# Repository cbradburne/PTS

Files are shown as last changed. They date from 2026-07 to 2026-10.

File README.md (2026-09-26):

# PTS — Pan / Tilt / Slider

A five-mount motorised camera system for live video production — wireless,
self-healing, and controllable from everything in the booth: a PC app with
joystick and CV tracking, phones, a 7″ touchscreen, Stream Decks via Bitfocus
Companion, and QLab cue stacks.

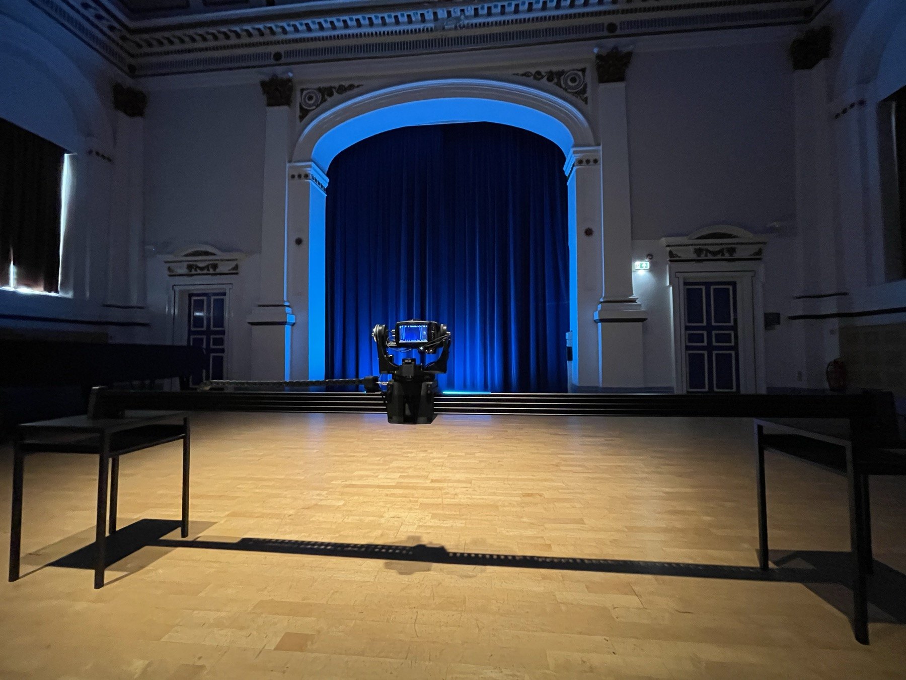
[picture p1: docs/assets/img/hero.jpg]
The rig in production — five mounts, hub console, one operator.


🌐 **[Project site](https://cbradburne.github.io/PTS/)** ·
📄 **[Two-page overview + OSC reference (PDF)](docs/PTS_Overview.pdf)** ·
🎛 **[Companion / QLab setup](docs/companion.md)** ·
📐 **[Look-at tracking design notes](DESIGN_V2.md)** ·
📡 **[What travels between a mount and the hub](docs/link_traffic.md)**

---

## What it does

- **Four axes per mount** — pan, tilt, slider, zoom (stepper or LANC) on
  TMC2209 silent drivers with StallGuard sensorless homing
- **Look-at tracking** — calibrate a subject's 3D position in two taps; the
  camera keeps aiming at it while the slider travels, and you can switch
  subjects mid-move from any controller
- **CV tracking** — the PC app watches the camera's feed and drives pan/tilt
  to keep a subject framed (optical-flow point tracking, or YOLO person
  detection with `ultralytics`); the operator keeps manual control of slider
  and zoom at the same time via a dedicated axis-mask jog mode
- **10 stored positions per mount** — recall from any surface at any speed
  preset; positions live on the mounts, so controllers can come and go
- **Zero-config pairing** — no MAC addresses, no per-unit firmware builds:
  hold a mount's screen, tap CAM 1–5, tap your hub. The hub learns mounts on
  first contact; conflicts resolve with one tap on the hub display
- **Self-healing** — autonomous recovery ladders on hub and mounts, idle
  maintenance restarts, watchdogs at every layer, and a motion-side dead-man:
  a mount stops within 500 ms of losing its control stream
- **Health telemetry** — every node reports heap, loop timing, link quality
  and reset cause into the PC log; degradation is visible hours before it
  becomes a symptom
- **Show-control** — OSC servers on both the hub and the PC app: every
  function on Companion buttons and QLab network cues

## Architecture

```mermaid
flowchart TB
    subgraph surfaces [Control surfaces]
        PC[PC app - PyQt6, joystick, CV tracking]
        WEB[Web app - phones]
        DISP[7in hub touchscreen]
        OSC[Companion / QLab - OSC]
    end
    HUB[HUB - Waveshare ESP32-S3-ETH<br/>Ethernet W5500 · WiFi AP PTS-name<br/>TCP 7777 · WebSocket · OSC 9700 · display UART]
    PC -- TCP / USB --> HUB
    WEB -- WebSocket --> HUB
    DISP -- UART --> HUB
    OSC -- UDP 9700 --> HUB
    HUB -- ESP-NOW star --> M1 & M2 & M3
    HUB -- Ethernet --> SAT[Satellite ESP32-S3-ETH<br/>one per distant room]
    SAT -- ESP-NOW --> M4 & M5
    subgraph mount [Each mount]
        M1[Bridge ESP32<br/>1.75in AMOLED]
        T1[Teensy 4.1 + TMC2209<br/>pan · tilt · slider · zoom]
        M1 -- UART --> T1
    end
    M2[CAM 2] ~~~ M3[CAM 3]
    M4[CAM 4] ~~~ M5[CAM 5]
```

| Part | Hardware | Firmware |
|---|---|---|
| Hub | Waveshare ESP32-S3-ETH (W5500 Ethernet, PoE variant) | [`firmware/esp32_hub_eth`](firmware/esp32_hub_eth) |
| Satellite | Waveshare ESP32-S3-ETH — extends ESP-NOW to another room over the wire | [`firmware/esp32_satellite`](firmware/esp32_satellite) |
| Hub display | Waveshare ESP32-S3 Touch LCD 7″ (800×480, LVGL 9) | [`firmware/esp32_display`](firmware/esp32_display) |
| Mount bridge | Waveshare ESP32-S3 Touch AMOLED 1.75″ (466×466 round, LVGL 9) | [`firmware/esp_mount_amoled175`](firmware/esp_mount_amoled175) |
| Motion controller | Teensy 4.1 @ 600 MHz, TMC2209 ×4, TeensyStep4 | [`firmware/teensy41_mount`](firmware/teensy41_mount) |
| PC app | Python 3.11+, PyQt6, OpenCV (+ optional YOLO) | [`pc_app`](pc_app) |
| Web app | Served by the hub itself — join its `PTS-<name>` WiFi | embedded in [`web_app.h`](firmware/shared/web_app.h) |

One binary per board type — **no per-unit configuration anywhere in source**.
Identity, pairing and calibration live in NVS/EEPROM, set from touchscreens.

## Hardware

Motion is NEMA 17 and NEMA 14 pancake steppers on TMC2209 drivers, geared with
GT2 belts and pulleys, off a single 12 V 8 A supply. The
[**bill of materials**](https://cbradburne.github.io/PTS/manual/bom.html) lists
every part with a buy link, broken down by assembly — circuit, mount, slider,
hub, display — including both the HDMI and SDI variants.

| | |
|---|---|
| [Bill of materials](https://cbradburne.github.io/PTS/manual/bom.html) | Motors, drivers, belts, pulleys, power, connectors, fasteners |
| [`Print Files/`](Print%20Files) | STEP models — PT mount and slider |
| [`PTS_4_PCB_2026-05-26.zip`](PTS_4_PCB_2026-05-26.zip) | PCB fabrication files |

> 🔧 *Still to write: assembly instructions, and a wiring diagram. The parts and
> the board are documented; how they physically go together is not.*

## Building the firmware

**Arduino IDE:** board settings and pinned library versions are documented in
[`libraries/README.md`](libraries/README.md) — copy the `libraries/` folders
into your Arduino libraries directory.

**Command line:** with `arduino-cli` installed (`brew install arduino-cli`),
one command compiles everything against the repo-pinned libraries:

```sh
tools/build.sh                      # every target
tools/build.sh hubeth display       # a subset
tools/build.sh flash hubeth [port]  # compile + upload
```

First-time bring-up: flash hubeth and the mounts, power up, then pair each mount
from its own screen (hold ~1.5 s → CAM number → pick hub → SAVE). The hub
needs no action. See the pairing sections in the firmware sources.

## Running the PC app

```sh
cd pc_app
python3 -m pip install -r requirements.txt
python3 -m pip install opencv-contrib-python   # + `ultralytics` for YOLO tracking
python3 main.py
```

Connects to the hub over USB serial or TCP (`Config` dialog). Includes
joystick control, position management, look-at calibration, CV tracking, and
an OSC server for Companion/QLab (UDP 9700).

## Show control (Companion / QLab)

Point a **Generic: OSC** connection at the hub (`192.168.4.1:9700`) or the
PC app machine — same `/pts/...` addresses on both, full reference in
[`docs/companion.md`](docs/companion.md) and the [PDF](docs/PTS_Overview.pdf).

```
/pts/cam/2/goto 3        recall shot 3 on camera 2
/pts/cam/1/jog -400 0 0 0   (press) … /pts/cam/1/jog/stop (release)
/pts/estop               stop everything
```

## Development

- **Protocol single source of truth** — [`firmware/shared/protocol.h`](firmware/shared/protocol.h)
  is canonical; `tools/check_protocol.py` verifies the Python and JS mirrors
  and cross-checks the *compiled C encoders* against the Python decoders
  byte-for-byte (golden vectors). Runs from the pre-commit hook:
  `git config core.hooksPath .githooks` after cloning.
- **Mount simulator** — develop the PC app with zero hardware:
  `python3 tools/mount_sim.py`, point the app at `127.0.0.1`. Includes a
  fault-injection console (link wedges, NACKs, packet loss) and `--selftest`.
- **Host test suites** — `tools/run_tests.sh` (or `tools/run_tests.sh cam` for a
  subset). No rig needed. Several of these read the FIRMWARE SOURCE and check
  the PC app against it — the command byte literals in `esp32_hub_eth.ino`, the
  loop-section enum in `esp32_satellite.ino` whose *order* is the wire
  encoding. That is deliberate: both halves of this rig have been wrong at the
  same time and agreed with each other, which is exactly what comparing one
  copy against another copy cannot catch.

  The end-to-end OSC test that lived here is gone with the PC app's OSC server —
  the OSC surface is the hub's now, so there is no host-side path to drive.

## Repository layout

```
firmware/
  shared/               canonical protocol, display UART framing, the web app
  esp32_hub_eth/        hub, for both boards: ESP-NOW star, AP, TCP/WS/OSC,
                        self-recovery — plus Ethernet and satellites on the
                        Waveshare ESP32-S3-ETH, WiFi-only on the XIAO ESP32S3
  esp32_satellite/      relay: extends ESP-NOW to another room over Ethernet
  esp32_display/        7" hub touchscreen (LVGL 9)
  esp_mount_amoled175/  mount bridge + round touchscreen, pairing UI
  teensy41_mount/       motion control: TMC2209, StallGuard, look-at solver
pc_app/                 PyQt6 controller: joystick, positions, look-at, CV, OSC
libraries/              pinned Arduino library versions (see its README)
tools/                  build.sh, protocol checker, simulator, tests, PDF gen
docs/                   Companion guide, overview PDF
Print Files/            STEP models        PTS_4_PCB_*.zip   PCB fab files
```

## License

**[PolyForm Noncommercial 1.0.0](LICENSE.md)** — in plain English:

- ✅ **Fork it, modify it, build it, share it** — free for any noncommercial
  purpose (personal, hobby, research, education), as long as the license and
  the copyright notice (which links back to this repository) stay with it.
- 💬 **Selling a product that uses any part of this?** That needs a separate
  commercial license — I'm open to discussion: contact
  [@cbradburne](https://github.com/cbradburne).

The license text in [LICENSE.md](LICENSE.md) is what governs; the bullets
above are just the summary.

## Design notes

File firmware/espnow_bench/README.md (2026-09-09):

# espnow_bench — finding the TX wedge

Two boards on a desk, both on USB serial, existing only to reproduce and then
kill the ESP-NOW transmit wedge that takes a mount off the air.

## What you need

| | board | why that one |
|---|---|---|
| **TX** — the mount | an **AMOLED** bridge board (spare, or one off a mount) | It is the board that wedges. The `load` experiment puts back the PSRAM/display work this firmware leaves out, and that only means something on the same silicon. |
| **RX** — the hub | **any ESP32-S3** — a hub-eth board, a satellite, or a plain S3 devkit | It only has to receive and ACK. It is not the suspect. |
| | **two USB cables to the same PC** | Both boards logged on one clock. See below — it is what answers the question. |

Nothing else. No Teensy, no display panel needed on the AMOLED, no hub, no
network. The two boards can sit a foot apart on a desk.

```bash
tools/build.sh flash bench   /dev/cu.usbmodemAAAA    # the AMOLED  (OPI PSRAM)
tools/build.sh flash benchrx /dev/cu.usbmodemBBBB    # the S3      (no PSRAM)
```

Two targets because the FQBNs differ — an AMOLED build flashed to a board with
no octal PSRAM does not boot. Same source either way.

### Which board needs to know what

Only the **TX** board needs a MAC typed at it. ESP-NOW registers a peer to
*send*; receiving needs nothing — an unencrypted frame reaches the receive
callback whatever the sender is, and the 802.11 ACK that decides the sender's
callback status is generated by the WiFi hardware for any frame addressed to
that MAC, before ESP-NOW is involved at all.

The RX board is passive by default. Turn `poll` on and it sends too — but it
still needs no MAC from you: it learns the TX board's address from the first
frame that arrives and registers that. There is no second MAC to get wrong.

What both boards **do** have to agree on is the **channel** (`chan`, default 1).
That is the one setting a silent link usually comes down to.

You do not need a separate terminal for any of this — **the logger types at both
boards for you** (see below), and it records what you typed into the run file.
Start it first, then set the boards up through it:

```
rx role rx                     # the receiver reboots and prints ITS OWN MAC
role tx
peer AA:BB:CC:DD:EE:FF         # <- that MAC. The RECEIVER's, not the TX's.
go
```

Plain text goes to the TX board; prefix with `rx ` for the receiver.

**`peer` is who the board sends TO.** On the TX board that is the *receiver's*
MAC — the one the RX board printed a moment ago. You never type a peer at the RX
board: passive it needs none, and polling it learns one. Typing the TX's own MAC
there is the easy mistake and it looks exactly like a dead radio, so the board
refuses it and says why.

On the RX board `role rx` makes it reboot and print its MAC, say it needs
nothing from you, and then:

- announces the first frame it gets, and which MAC it came from, so you know the
  link is up rather than guessing;
- if nothing arrives, says so every 30 s with its own MAC and channel, which is
  the check you would otherwise have to think of yourself.

On the TX board:

```
role tx
peer AA:BB:CC:DD:EE:FF
rate 50
go
```

Both boards persist their settings in NVS, so an overnight run survives a power
cut and resumes where it was. `help` lists every command.

### Reboot between leak runs

**`go` zeroes the counters. It does not give the stack back the buffers it
lost.** Only a chip reboot does — that has been the one fixed point of this
fault since August, and it applies to the bench exactly as it does to a mount.

So a second leak run on the same power cycle starts however many buffers down
the last one ended, with `floor` measuring from a false zero. It happened
immediately after the first reproduction: `go`, and `in_flight` read 3 from the
first sample to the last, never moving — the previous run's damage, not the new
run's. The board now says so when you `go` with a non-zero floor behind you.

Power cycle both boards, or `role tx` / `role rx` which reboot — then **`go` on
each**. `role` clears the run flag deliberately, so a board whose role just
changed does not come back transmitting; the cost is that the reboot looks like
the whole job and the pair comes up configured, linked and silent. Both boards
now say `STOPPED` on boot when that is where they are.

## Logging both boards

```bash
python3 -m pip install pyserial
tools/bench_log.py --tx /dev/cu.usbmodemAAAA --rx /dev/cu.usbmodemBBBB \
                   --tag cap0-rate50
```

(`python3 tools/bench_log.py …` works too, and is what to reach for if the
executable bit has not survived however the repo reached your machine.)

The logger holds both serial ports, so it is also the only thing that can talk
to the boards while it runs — type at it directly. `newfile [tag]` closes the
CSV and opens a fresh one **without touching the boards**, which is what you
want when the variable under test changes mid-session (`cap 2` on top of a load
that leaks, say). Restarting the logger would also start a new file, but it
drops the samples either side of the gap and resets the receiver baseline and
the deltas the arriving-without-callbacks alarm is built on. Each file names the
other, so neither is a fragment of unknown origin. Everything you type is
written into the CSV as well as onto the wire, which matters more than it
sounds: **"cap 1 at t=3600" is the single most important thing a comparison
needs, and the easiest to forget you did.** A run file that does not say what
was varied is not evidence.

One logger, both boards, one PC clock across the pair — which is not
convenience, it is the only way to ask the question the bench exists for:

**when the callbacks stop, are the frames still arriving?**

- **arriving, no callbacks** → the radio is fine and the *callback* is the fault.
  The pool leaks because buffers are never returned, not because sends fail.
- **frames stop too** → the transmit path really is down and the callback is
  telling the truth.

Those want opposite fixes, and the TX board alone cannot tell them apart — its
counters go quiet either way. The logger says which, in as many words, at the
end of every run.

Runs land in `bench-logs/` as CSV. Compare them:

```bash
tools/bench_log.py --compare bench-logs/*.csv
```

```
run                       mins   issued   lost  floor  rx_got  1st ref  wedged
cap0-rate50-...csv         9.8    30000  15000  14995   29500     410s    410s
cap1-rate50-...csv       840.0  2520000      3      0 2519997    never   never
```

That table is the deliverable. Two runs differing in one variable is a finding;
one run on its own is an anecdote.

## What the numbers mean

One line a second from the TX board:

```
t=612s issued=30600 cb_ok=30594 cb_fail=0 refused=0 nomem=0
       in_flight=6 floor=0 max=9 rx=0 heap=284512 err=0x0 cmd=1220 ack=1220 ovl=47
```

`cmd` is commands received, `ack` the replies sent for them, and **`ovl` is the
number of times `in_flight` went above 1** — two buffers out of the pool at once.
All three read 0 unless `poll` is on.

`ovl` is the first thing to look at with `poll` running. **`ovl` still 0 means no
overlap and the run is testing nothing new.** It is counted per transition and
sampled every loop pass, which matters: an overlap lasts about a millisecond, so
anything sampled once a second sees almost none of them.

It counts transitions above **the floor**, not above 1, so that it keeps meaning
the same thing once buffers start leaking. Measured against a fixed 1 it stopped
counting the moment the floor reached 2 — the first leak run froze `ovl` for its
last thirteen hours and read as "overlap stopped" when nothing of the sort had
happened.

**`in_flight = issued − (cb_ok + cb_fail)`** is the whole point. It is the number
of buffers `esp_now_send()` has taken from the stack's pool that the
send-complete callback has not yet given back.

- It bouncing between 0 and a few is **normal** — that is just sends in flight.
- **The heap is the second witness, and the one that settles an argument.** A
  real leak costs a fixed number of bytes per buffer and never gives them back
  — 208 on these boards, three times over in the run that reproduced it. A floor
  that rises while the heap returns to its old value is not a leak; it is a
  callback that came back late, or a `go` issued while sends were outstanding.
  Check both before believing either.
- **`floor` is the number to watch.** It is the lowest `in_flight` has returned
  to in the last five seconds, and it only ever rises. A floor that climbs and
  never comes down is buffers being *lost*, not buffers in use. That is the leak,
  and you are watching it happen — hours before `nomem` moves.
- `nomem` climbing means the pool is already empty. By then it is over.

The rig has never had `floor`. It only ever had `refused`, which cannot warn:
a refusal means the radio will not accept a send, so the report carrying the
number is the one thing that cannot go out. cam1's own health report 18 seconds
before it wedged read zero.

## Runs so far

**The third run reproduced it. It is the load.**

| run | config | for | sent | floor | outcome |
|---|---|---|---|---|---|
| `…0905-1822` | rate 50, cap 0, no load | 3.0 h | 542,067 | 0 | clean |
| `…0905-2313` | rate 200 + poll 20, cap 0, no load | 13.3 h | 10,512,753 | 0 | clean |
| `…0906-1238` | **the same, plus `load 40 100`** | 20.1 h | 10,123,186 | **0 → 4** | **LEAKED** |
| `…0907-0851` | `load 100 200`, cap 0 | 6.8 h | 2,944,102 | 0 | clean (short) |
| `…0907-1558` | **`load 40 100` + `cap 2`** | **53.3 h** | **26,868,324** | 0 | **clean** |

The third differs from the second in one thing: 40 ms of blocked loop in every
100. Same cap, same PHY, same peer, same boards, 10 million sends either way.

The fifth differs from the third in one thing: `cap 2`. Same load, same rate to
within 1% (140.0 sends/s against 138.6), same boards, same PHY.

**Run to 2026-09-09, 53.32 h, one continuous session:**

| | uncapped `…0906-1238` | `cap 2` `…0907-1558` |
|---|---|---|
| ran for | 20.09 h | **53.32 h** |
| sends | 10,123,186 | **26,868,324** |
| peak in flight | **7** | **2** |
| overlaps / 1000 sends | 43 | **101** |
| buffers lost | **4** | **0** |
| heap drift | **−832 B** | **0 B** |
| `cb_fail` / `refused` / `nomem` | — | **0 / 0 / 0** |

Not one callback missing in 26.9 million sends, and the heap ended on the same
byte it started: 265,724 → 265,724.

The uncapped run lost a buffer every 2.53 M sends. At that rate the capped run
should have lost **10.6**. It lost none: **p ≈ 2.4 × 10⁻⁵**, about 1 in 42,000.

And note the overlap column, because it answers the obvious objection. `cap 2`
did not win by transmitting less concurrently — it overlapped sends **more than
twice as often per send** as the run that leaked (101 per 1000 against 43). What
it bounded was the DEPTH. Sends overlapping is not the fault; three or more
overlapping is.

It has also now gone **8.9× the sends the uncapped run needed to lose its first
buffer** (3.0 M) without losing one. That is prevention, not delay — as far as
53 hours can show it.

### It needs BOTH, and that is the mechanism

| | load | peak in flight | result |
|---|---|---|---|
| 13.3 h | none | 5 | clean |
| **53.3 h** | 40/100 | **2** | clean |
| 20.1 h | 40/100 | **7** | **4 buffers gone** |

Blocking alone does not do it. Concurrency alone does not do it. Both together
do — and on the mount they are not independent, because **the block is what
creates the burst.**

`esp_mount_amoled175.ino:3525` drains the ESP-NOW receive queue unbounded:

```c
while (xQueueReceive(_espnow_rx_q, &en_msg, 0) == pdTRUE) {
    ... handle_hub_packet(pkt);      // an ACK per non-JOG packet, line 1357
}
```

`ESPNOW_RX_DEPTH` is 16. An LVGL flush blocks the loop; commands from the hub
queue up behind it; the loop resumes and fires up to sixteen ACKs back to back
with no cap and no pacing. That is a burst the average send rate (0.4/s idle,
10.4/s busy) gives no hint of, and it is exactly the condition these runs show
leaking.

**So the fix is on the mount and it is small: bound that drain.** Handling two
packets per loop pass instead of all sixteen leaves the rest queued for the next
pass microseconds later — no frames dropped, and never more than a couple of
sends outstanding. That is what `cap 2` did here.

Statistics, honestly: one run, zero events where about three were expected —
p ≈ 0.05. Suggestive on its own. What makes it more than suggestive is that the
mechanism is visible in the bridge's source.

### The signature

| | at | heap after | change |
|---|---|---|---|
| floor 0 → 1 | 5.97 h | 265,516 | **−208 B** |
| floor 1 → 2 | 6.28 h | 265,308 | **−208 B** |
| floor 2 → 3 | 15.17 h | 265,100 | **−208 B** |
| floor 3 → 4 | 20.04 h | 264,892 | **−208 B** |

**Exactly 208 bytes per lost buffer, four times, never returned** — 832 bytes
gone by the end of the run.

The control's heap moved 24 bytes in 13.3 hours and its floor never left 0. The
`cap 2` run did better still: **0 bytes in 53.3 hours**, ending on the same byte
it started.

This is what the field data pointed at all along: cam1 wedged twice on the
**strongest link on the rig** (−33 dBm) while cam4 sat at −68 dBm through a
satellite and never did. A radio explanation has that backwards. Starving the
loop does not.

### What it means for the mount

The mount renders 37 KB draw buffers out of PSRAM on this same chip. A blocked
loop is a blocked loop whether an LVGL flush or a `nop` spin is doing the
blocking — so the suspect is now the display work, not the radio, and the fix
is on that side: shorter flushes, yielding during them, or getting the ESP-NOW
callback out from behind the Arduino loop task.

Rate is explained too, and it was never really about the send count: more
traffic means more callbacks due during each block, and it is the callback that
returns the buffer. Cutting a satellite's traffic 88% cut its exposure by the
same factor — which is why that worked without anyone knowing why.

### Still open

- **Is it block length or duty cycle?** `load 40 400` (same 40 ms block, a
  quarter of the duty) against `load 10 100` (same duty, 10 ms blocks) separates
  them, and the answer decides the fix: if it is block length, chunking the
  flush is enough.
- **Does `cap` prevent it?** Fewer sends outstanding means fewer callbacks
  queued behind the block. §4 tests it directly, and it would be a small change
  to `espnow_tx()`.

First, though, make it faster — see §5.

### Read against the rig

cam1 wedged after 31.1 h and again after 11.4 h:

- The second run ran **longer than the shorter wedge** and sent **24× more
  frames** than cam1 could have managed in that time even at a flat-out
  10.4 sends/s. Not volume.
- It also stacked **486,030 overlapping sends, five buffers deep**, without
  losing a single one — 957,735 commands, 957,735 replies, none unanswered, and
  every send matched by its callback. Not concurrency, and not reply-on-arrival.
- `floor` sat at 0 for all 47,889 samples and the heap drifted **24 bytes in
  thirteen hours**. Whatever the mount is doing, this is not it.

Add 40 ms of blocked loop and it leaks in six hours at a *lower* send rate. So
none of volume, concurrency or reply-on-arrival is the mechanism — they are the
traffic the mechanism acts on.

Together with what was already known, the field is now:

| ruled out | how |
|---|---|
| RF / link quality | clean for hours at −80 dBm while collapsing at −76; cam1 wedges at −33 dBm, cam4 never at −68 dBm |
| BLE / WiFi coexistence | the wedge predates the Blackmagic code existing at all. Secondarily: the wedge logs come from the work rig, where cam1 has no camera paired, and an unbonded mount never scans |
| send volume | 542k sends, then 10.5M, nothing — and it later leaked at a *lower* rate |
| overlapping sends | 486k overlaps five deep, nothing |

| **confirmed** | **how** |
|---|---|
| **a blocked loop** | same rates, same cap, plus `load 40 100`: floor 0 → 3, 208 bytes gone each time, `in_flight` never below 3 again |

## The experiments, in order

Each one changes exactly one thing. Run the baseline first so you know what
"not wedging" looks like on your bench.

### 1. Baseline — does it reproduce at all?

```
cap 0        # fire and forget, exactly what the mount does today
rate 50
phy lr       # 1 Mbps long preamble, as the rig runs
load 0 0
scan 0
go
```

Leave it. The rig takes 11–31 hours; the bench may be faster because there is
nothing else competing. If `floor` stays at 0 for a day, the send stream alone
is **not** the cause and the answer is in one of the variables below.

**Done — clean.** 542,067 sends in 3.0 h, `floor` 0. The send stream alone is
not the cause.

### 2. Overlap — the one the first run pointed at

The baseline came back clean: **542,067 sends in 3 h at 50 Hz, `floor` 0, every
send answered by its callback.** That is more sends than cam1 could have made
before its 11.4-hour wedge even at a flat-out 10.4/s, so a plain per-send leak
is out.

But look at what that run could not test: **`in_flight` never once exceeded 1.**
Frames 20 ms apart, each clearing in about a millisecond — they never touch. One
buffer out of the pool, ever.

The rig is not shaped like that. The bridge runs reports on timers *and* answers
every non-JOG command the instant it arrives, so a command landing mid-report
puts a second buffer in the pool on top of the first. That happens all day on a
mount and had never once happened on this bench.

```
rx poll 20        # the RECEIVER sends commands; the TX must answer each
rx go             # the RX needs 'go' too now — it is sending
```

Both boards then report `cmd=` and `ack=`, and the TX prints **`OVERLAP`** the
first time two sends are outstanding at once. If it instead prints `NO OVERLAP
after 60s`, the run is still a metronome — raise `poll` until it does. Check
that in the first minute; it is the whole point of the run.

This also reconciles the two facts that otherwise fight each other. Overlap
scales worse than linearly with traffic, so an 88% cut removes far more than 88%
of it — which is how "rate matters" and "half a million evenly spaced sends did
nothing" can both be true.

`poll 0` restores the previous behaviour exactly, so the pair differs in one
variable.

**Done — clean.** 13.3 h at `rate 200` + `poll 20`: 10,512,753 sends, 486,030
overlaps up to five deep, `floor` 0, every command answered. Not concurrency.

One thing that run taught about tuning it: overlap does not scale smoothly with
the rates. Going from `rate 50`+`poll 20` to `rate 200`+`poll 20` — 4× the data
rate — took overlap from 0.05/s to **10.4/s**, roughly 200×. It behaves like a
threshold: at 20 ms spacing sends essentially never touch, at 5 ms they touch
constantly. So if `ovl` is not moving, raise `rate` rather than nudging `poll`.

### 3. Rate — is it really rate?

Cutting a satellite's traffic by 88% took it from 36 restarts in 17 hours to
zero, so rate is the strongest clue there is. Run `rate 10`, `rate 50`,
`rate 200` and record time-to-first-refusal for each. If the time scales with
rate, it is a per-send leak and the arithmetic will tell you the leak rate per
thousand sends.

Partly answered, and awkwardly: 220 sends/s for 13.3 h did nothing, so on the
bench rate does not reproduce what it plainly governs on the rig. Whatever rate
is a proxy for out there, it is not the send count and not the overlap.

### 4. The cap — is the fix three lines?

```
cap 1        # never a second send outstanding — the textbook ESP-NOW discipline
```

The mount today calls `esp_now_send()` with no regard for how many sends are
outstanding, and `espnow_tx()` says so in as many words: *"none of them can do
anything useful about a refusal in the moment"*. If `cap 1` (or 2, or 4) stops
the floor rising where `cap 0` does not, **that is the fix**, and it is a small
change to `espnow_tx()`.

Worth running now that §5 gives something to prevent: keep `load 40 100` and add
`cap 2`. Fewer sends outstanding means fewer callbacks queued behind each block.
A run that leaks without a cap and not with one is the whole answer.

### 5. Load — is it the display, not the radio?  ← **THIS ONE REPRODUCED IT**

Everything above came back clean, which promoted this one: it was the largest
thing the bench did not have. `rate 200` and `poll 20` left exactly as they
were, so the 13.3 h clean run is its control and load the only difference.

**Result: floor 0 → 3 in 20 h, 208 bytes gone each step.** See *Runs so far*.

What is left is to make it FASTER, because every experiment from here costs a
night at six hours to first leak. Push the block length up:

```
load 100 200     # 100 ms blocks, half the time
```

If time-to-first-leak drops with it, that is both a faster bench and evidence
that block length — not duty cycle — is the variable. Then `load 40 400`
(same block, quarter the duty) against `load 10 100` (same duty, short blocks)
separates the two properly, and the answer decides the fix on the mount: if it
is block length, chunking the LVGL flush is enough.

```
cap 0
load 40 100      # block the loop 40 ms in every 100 — a heavy LVGL flush
```

The mount renders 37 KB draw buffers out of PSRAM on this same chip, and the
firmware already notes that rendering is bandwidth-bound. If starving the loop
leaks buffers, the display is the cause and the radio is innocent.

**This is the hypothesis the field data points at.** cam1 wedged twice at
−33 dBm — the strongest link on the rig — while cam4 sat at −68 dBm through a
satellite and never did. A radio-quality explanation has that backwards; a
"cam1's screen is doing more work" explanation does not.

Try `load 10 100`, `40 100`, `100 200`. If there is a threshold, find it.

### 6. Scan — does retuning the radio drop callbacks?

```
load 0 0
scan 30
```

A scan retunes the radio out from under an in-flight send.

Read the history before spending a night on it. The mount used to scan every
five minutes for the life of the run, and that was found and removed — an
overnight log caught **174 failures, one every 300 s to the second**, phase
locked to the mount's boot, ~100–150 `txfail` in a burst each time. But those
were the hub misreading a run of failures as a wedge and refreshing the peer,
not the NO_MEM fault: `esp_mount_amoled175.ino` around the `[REACQ]` block has
the whole account.

Since then the bridge scans only **at boot** or when its base has gone
**silent**, so a mount with a healthy hub link does not scan at all. That makes
it a poor fit for cam1, whose link was the strongest on the rig — unless the
link went quiet first, which is worth checking in the logs before testing it
here.

### 7. PHY rate

```
phy def      # then reboot
```

1 Mbps with a long preamble buys 6–10 dB of range and makes every frame roughly
eight times longer on air. Longer frames mean longer in flight, and more of them
outstanding at the same send rate.

## What a finding looks like

Something that separates two runs differing in one variable, with a mechanism:

> `cap 0` at 50 Hz: floor reaches 11 in 40 minutes, first refusal at 71 min.
> `cap 1` at 50 Hz: floor 0 after 14 hours.
> → the leak is per-outstanding-send, and bounding in-flight prevents it.

That is enough to change `espnow_tx()` and put a number on the expected
improvement before touching the rig.

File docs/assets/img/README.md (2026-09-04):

# Site images

Drop photos/screenshots here with these exact filenames and the matching
slot on the site fills itself in (no HTML edits needed):

| File | Where it appears |
|---|---|
| `hero.jpg` | Hero — the rig in production (landing page) |
| `mount-pole.jpg` | Mounts — head on a clamp, built without the slider |
| `mount-home.svg` | Mounts — the round AMOLED status screen |
| `hub-home.svg` | Hub — the 7" touchscreen home screen |
| `phone-landscape.png` | Hub — the web app on a phone |
| `lookat-move.mp4` | Look-at — a move mid-travel (video, with `.jpg` poster) |
| `cv-window.png` | CV tracking — the tracking window with a lock-on target |
| `pc-app.png` | Control surfaces — PC app screenshot |
| `move-panel.png` | Control surfaces — the Move panel |
| `cad.png` | Build it — CAD model |
| `pcb.jpg` | Build it — the mount PCB |

Landscape ~1600px wide works best; JPG for photos, PNG for screenshots.

## Video

Clips are 960×540 H.264 MP4, no audio, `-movflags +faststart`, ~1.5 MB per
40 s — small enough to sit in the repo, and they play inline everywhere
(`muted` + `playsinline` is what lets iOS Safari play them in the page). Each
has a same-named `.jpg` poster frame, pulled from the encoded clip.

Keep the **camera master out of git** — `docs/assets/img/*.mov` is gitignored.
Binaries don't delta-compress, so a master committed once stays in history
forever. Encode to MP4 in a scratch directory, check it, then commit only the
final file. To re-encode from a master:

```
ffmpeg -ss <start> -to <end> -i master.mov -an \
  -vf "fps=24,scale=960:540:flags=lanczos" \
  -c:v libx264 -preset slow -crf 31 -pix_fmt yuv420p \
  -profile:v main -movflags +faststart -g 48 out.mp4
```

## Manual pages

Pages under `docs/manual/` use the same self-filling photo-slot convention.
So far:

| File | Where it appears |
|---|---|
| `rig-overview.jpg` | Getting started — a whole rig |
| `mount-home.svg` | The mounts — round AMOLED status screen |
| `mount-level.svg` | The mounts — spirit-level screen |
| `mount-setup.svg` | The mounts + Pairing — Setup screen |
| `hub-home.svg` | Hub touchscreen — home screen (hero) |
| `hub-positions.svg` | Hub touchscreen — Positions screen |
| `hub-detail.svg` | Hub touchscreen — per-camera control |
| `hub-config.svg` | Hub touchscreen — Config screen |
| `hub-pairing.svg` | Hub touchscreen — Paired Mounts |
| `phone-portrait.png` | Web app — phone in portrait (hero) |
| `phone-landscape.png` | Web app — phone in landscape |
| `ipad-landscape.png` | Web app — extended view on a tablet |
| `lookat-move.mp4` | Look-at — a full move, camera POV |
| `lookat-reaim.mp4` | Look-at — re-aiming to a second subject mid-move |
| `slider-rail.mp4` | The mounts — the head travelling its rail |
| `mount-rail.jpg` | The mounts — the head on its slider rail |
| `mount-pole.jpg` / `mount-pole2.jpg` | The mounts — the slider-less clamp build |
| `slider-production.mp4` | The mounts — slider move during a live set |
| `slider-venue.mp4` | The mounts — the same rig from the back of the hall |

The hub and mount screens are SVG recreations of the 7" console and the 1.75"
round AMOLED rather than photographs — they stay crisp at any size and are far
smaller than a photo of a panel. Round mount screens use the `round` figure
class so the square artwork is capped and centred. The
phone/tablet web-app shots are clean screen captures, so PNG. More slots will be
added as manual sections are written.

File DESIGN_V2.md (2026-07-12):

# Camera Mount Controller — Version 2 Design

## What's new in v2

V2 adds **look-at tracking**: the camera continuously aims at a named subject
in 3D space while the slider moves independently.  Pan and tilt become
*derived* values — computed from the current slider position and the
subject's calibrated 3D world coordinates — rather than independent motor
targets.

V1 is preserved in `/Users/col/New CC` and remains fully functional.

---

## Coordinate system

```
                         Z  (away from rail, into room)
                         │
               subject ──┼──────────────────●  (sx, sy, sz)
                         │               ╱
                         │            ╱  look-at vector
                         │         ╱
  Y (up)                 │      ╱
    │                    │   ╱
    │   slider rail ─────●──────────────────▶  X (along rail)
    │                  cam at
    └──────────────────  (slider_pos, cam_height, 0)
```

- **X axis** — along the slider rail; 0 = slider home (min limit)
- **Y axis** — vertical; 0 = camera pivot height (set at calibration)
- **Z axis** — perpendicular to rail, into the room (positive = toward subjects)
- All units: **millimetres**

### Look-at angles

Given current camera position `(cx, 0, 0)` and subject `(sx, sy, sz)`:

```
dx = sx - cx
dz = sz          (camera Z is always 0)
dy = sy          (camera Y pivot is 0 by definition)

pan_rad  = atan2(dx, dz)                       // horizontal
tilt_rad = atan2(dy, sqrt(dx*dx + dz*dz))      // vertical
```

These are converted to motor steps using the existing
`physToUSteps` / degrees-to-steps calibration.

---

## Subjects vs Slider Locations

The 10-slot grid is split into two independent concepts:

| Concept | Count | Stored on | Description |
|---|---|---|---|
| **Subjects** | up to 8 | Teensy EEPROM | 3D world coords of a person/object |
| **Slider moves** | up to 8 | Teensy EEPROM | Slider start+end position + speed |

A **shot** combines one slider move with one subject: "move the slider from
A to B while keeping the camera aimed at Subject 3."  Shots can be chained.

---

## Subject calibration workflow

1. User presses **"Add Subject"** (PC / hub / web)
2. Firmware auto-moves slider to `slider_min` (home)
3. UI prompts: *"Aim camera at subject, then press SET"*
4. User jogs pan/tilt to subject, presses SET →
   firmware records `(slider_pos_A, pan_steps_A, tilt_steps_A)`
5. Firmware auto-moves slider to `slider_max`
6. UI prompts: *"Re-aim camera at same subject, then press SET"*
7. User jogs pan/tilt, presses SET →
   firmware records `(slider_pos_B, pan_steps_B, tilt_steps_B)`
8. Firmware solves for `(sx, sy, sz)` from the two observations and saves
   to EEPROM.

### Solving for 3D position from two observations

At slider pos `xA`, camera aims along unit vector `vA`.
At slider pos `xB`, camera aims along unit vector `vB`.

Two rays in 3D space; solve for their nearest intersection
(least-squares, since real measurements won't be perfect):

```
Ray A:  P = (xA, 0, 0) + t * vA
Ray B:  P = (xB, 0, 0) + s * vB
```

This is a standard ray-ray closest-point problem solved with a 2×2 linear
system.  The midpoint of the shortest segment between the two rays is the
estimated subject position.

---

## New firmware state machine

```
STATE_IDLE
STATE_JOGGING            (unchanged from v1)
STATE_MOVING_TO_POS      (unchanged — used for simple GOTO)
STATE_FINDING_LIMITS     (unchanged)
STATE_LOOK_AT_MOVE       (NEW)
  └─ slider moves on its own profile
  └─ pan/tilt updated every LOOK_AT_INTERVAL_MS from current slider pos
  └─ subject can be switched mid-move (pan/tilt smoothly steers)
  └─ pan/tilt speed capped at LOOK_AT_MAX_PT_DEG_S (configurable)
STATE_CALIBRATING_SUBJECT (NEW)
  └─ sub-states: WAITING_POINT_A → MOVING_TO_B → WAITING_POINT_B → SOLVING
```

---

## Look-at controller (replaces moveTo for pan/tilt during a slider move)

Runs every `LOOK_AT_INTERVAL_MS` (20 ms = 50 Hz) inside `update()`:

```cpp
void MountMotion::_updateLookAt() {
    // 1. Get current slider position in mm
    float cx = stepsToMm(AXIS_SLIDER, _stepper[AXIS_SLIDER]->getPosition());

    // 2. Compute required pan/tilt angles
    float dx = _lookat_subject.x - cx;
    float dy = _lookat_subject.y;        // constant vertical offset
    float dz = _lookat_subject.z;

    float pan_rad  = atan2f(dx, dz);
    float tilt_rad = atan2f(dy, sqrtf(dx*dx + dz*dz));

    // 3. Convert to steps
    int32_t pan_target  = radToSteps(AXIS_PAN,  pan_rad);
    int32_t tilt_target = radToSteps(AXIS_TILT, tilt_rad);

    // 4. Speed-limited move toward target (follower-style)
    _driveTowardTarget(AXIS_PAN,  pan_target,  _lookat_max_pt_speed);
    _driveTowardTarget(AXIS_TILT, tilt_target, _lookat_max_pt_speed);
}
```

`_driveTowardTarget()` uses `rotateAsync()` + `overrideSpeed()` with a
speed proportional to distance, capped at `_lookat_max_pt_speed`.

---

## Pan/tilt absolute angle reference

### The problem

Pan and tilt have no hardware end stops.  On every power cycle the step
counter resets to zero at whatever physical position the head is in.  For
look-at tracking to work, the firmware must know: *"at this step count, the
camera is physically pointing at this angle."*

### How deg/step is established (once, at first calibration)

During subject calibration (2-point process), two observations of the same
subject from different slider positions give two known pan angles and two
known tilt angles with their corresponding step counts.  This yields:

```
pan_deg_per_step  = (pan_B_deg  - pan_A_deg)  / (pan_steps_B  - pan_steps_A)
tilt_deg_per_step = (tilt_B_deg - tilt_A_deg) / (tilt_steps_B - tilt_steps_A)
```

These are stored in EEPROM and never need recalculating unless the
mechanical drive ratio changes (e.g. gears replaced).

### The session reference ("Set Ref")

`deg_per_step` tells us the *scale* but not the *offset* — i.e. where in
physical angle terms step-count-zero currently sits.  This offset is
invalidated whenever the mount is powered off, or whenever someone physically
moves the head while powered on.

**Solution: a "Set Ref" button, available at any time from all interfaces.**

Workflow:
1. Operator aims the camera at any already-calibrated subject (or any known
   reference point with a stored subject record).
2. Presses **Set Ref** and selects the subject they are aimed at.
3. Firmware calculates the expected pan/tilt angles for the current slider
   position looking at that subject's 3D coords, then sets the step-count
   offset so the current step count maps to those angles.

There is no timer.  The button can be pressed:
- At the start of a session after powering on
- After physically repositioning the head
- Any time the operator suspects the reference has drifted
- Repeatedly on different subjects to verify consistency

If the reference is slightly off on the first try, the operator simply
re-aims and presses Set Ref again.  No move is commanded — the button only
updates the internal angle offset.

### Future: optical homing (Option A, hardware upgrade path)

Adding an optical end stop to pan and/or tilt would allow automatic homing
on power-on, making the Set Ref step unnecessary.  The firmware architecture
is designed to accommodate this — `setRef()` would simply become an
internally-called function after the home move completes rather than a
user-triggered one.  This will be investigated separately.

---

## New protocol commands (additions to v1)

| Command | Direction | Payload | Description |
|---|---|---|---|
| `CMD_ADD_SUBJECT_START` | PC→Mount | `subject_id (1B)` | Begin calibration for subject N |
| `CMD_ADD_SUBJECT_SET_A` | PC→Mount | — | Record point A (slider at home, pan/tilt current) |
| `CMD_ADD_SUBJECT_SET_B` | PC→Mount | — | Record point B (slider at max, pan/tilt current) |
| `CMD_ADD_SUBJECT_ABORT` | PC→Mount | — | Cancel calibration |
| `CMD_DELETE_SUBJECT` | PC→Mount | `subject_id (1B)` | Delete a subject |
| `CMD_SUBJECT_LIST` | Mount→PC | 8 × `{id, name[16], x,y,z floats}` | All subjects |
| `CMD_SET_REF` | PC→Mount | `subject_id (1B)` | Set pan/tilt angle reference using named subject at current slider pos |
| `CMD_SET_SLIDER_MOVE` | PC→Mount | `slot, start_mm, end_mm, speed_preset` | Store a slider move |
| `CMD_START_LOOK_AT_MOVE` | PC→Mount | `slider_slot, subject_id, max_pt_speed` | Start tracking move |
| `CMD_SWITCH_SUBJECT` | PC→Mount | `subject_id` | Switch target mid-move |
| `CMD_LOOK_AT_STATUS` | Mount→PC | `slider_pos_mm, pan_deg, tilt_deg, subject_id` | Live telemetry |
| `CMD_REF_CONFIRMED` | Mount→PC | `pan_deg, tilt_deg (2× float)` | Echoes computed reference angles so UI can confirm |

---

## EEPROM additions (v2)

```c
#define MAX_SUBJECTS   8
#define MAX_SLIDER_MOVES 8
#define SUBJECT_NAME_LEN 16

typedef struct {
    float x, y, z;           // world coords in mm
    char  name[SUBJECT_NAME_LEN];
    bool  valid;
} SubjectRecord;

typedef struct {
    int32_t start_steps;
    int32_t end_steps;
    uint8_t speed_preset;
    bool    valid;
} SliderMoveRecord;

// Added to EepromConfig:
SubjectRecord    subjects[MAX_SUBJECTS];
SliderMoveRecord slider_moves[MAX_SLIDER_MOVES];
float            slider_mm_per_step;   // set during findLimits (mm travel / total steps)
float            pan_deg_per_step;     // set during first subject calibration
float            tilt_deg_per_step;    // set during first subject calibration
```

The **session reference** (pan/tilt step-count offset) is held in RAM only —
it is intentionally not saved to EEPROM because it is always invalid after a
power cycle.  The operator sets it via the **Set Ref** button each session.

```c
// RAM only — not in EepromConfig:
static float _pan_ref_deg;      // physical pan angle at step count 0
static float _tilt_ref_deg;     // physical tilt angle at step count 0
static bool  _ref_set;          // false until Set Ref pressed at least once
```

Look-at moves are gated on `_ref_set == true`.  If the operator attempts a
look-at move before setting the reference, the firmware rejects it and sends
an error packet so all UIs can display a clear warning.

---

## PC app additions

- `config/subject_store.py` — load/save subject names (labels only; 3D
  coords live on Teensy EEPROM)
- `ui/dialogs/subject_calibration_dialog.py` — guided 2-point calibration
  workflow
- `ui/widgets/subject_grid.py` — replaces/extends `position_grid.py` with
  two tabs: Subjects and Slider Moves
- `comms/protocol.py` — new command IDs
- `comms/mount_manager.py` — new send methods for look-at commands

---

## Implementation order

1. **Protocol** — define all new command IDs in `shared/protocol.h` and
   `pc_app/comms/protocol.py`
2. **Teensy firmware** — add subject/slider-move EEPROM structs, new state
   machine states, look-at controller, calibration state machine, new
   command handlers
3. **PC app** — calibration dialog, subject grid widget, send commands
4. **Hub display** — subject selection buttons, look-at status overlay
5. **AMOLED display** — subject buttons on jog screen
6. **Web app** — subject selection and look-at controls

---

## What does NOT change from v1

- Jog (pan/tilt/slider/zoom) — identical
- Find limits / find home — identical
- Speed presets / orientation / stall thresholds — identical
- Config dialog — identical
- E-stop — identical
- CV tracking — carried forward unchanged
- LANC zoom — identical
- ESP-NOW wireless protocol between hub and mounts — identical

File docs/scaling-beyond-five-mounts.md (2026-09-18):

# Scaling past five mounts

Design note for supporting ten mounts now and more later, while the PC app, the
hub display and the web app each show five at a time and let the operator choose
which five.

Written 2026-09-18, before any of it is built.

## The short version

The wire protocol already supports it. The radio supports it. The cost is almost
entirely in the three user interfaces and in one whole-rig flash that cannot be
staged.

## What already works

```
mount_id            0x00 broadcast, 0xF0+ satellites, 0xFD display, 0xFE hub
                    ids 1..0xEF are free — 239 mounts
PACKET_MAX_PAYLOAD  256 bytes
MOUNT_TABLE         5 x MAC(6) = 30 B today; 10 needs 60; the ceiling is ~42 mounts
MOUNT_ROUTE         one byte per mount; irrelevant at any realistic size
OSC                 /pts/cam/N/... — N is already the mount id, not a slot
```

Nothing in the packet format needs redesigning, and OSC needs no change at all:
addressing by mount id means Companion, QLab and Stream Deck reach every mount
whether or not it is one of the five on screen. That is the behaviour wanted, and
it is what the code already does.

## The one hard ceiling

```
ESP_NOW_MAX_TOTAL_PEER_NUM = 20      per node, not per rig
```

Twenty *directly radioed* mounts per node. Satellites hold their own peer tables
and reach the hub over Ethernet, so the rig ceiling is 20 direct plus 20 per
satellite across 6 satellite slots. Ten is comfortable. Beyond roughly eighteen
direct, mounts have to be distributed across satellites by design rather than by
convenience.

## Two traps to clear before anything else

**The payload lengths are hardcoded literals.**

```c
#define MOUNT_TABLE_PAYLOAD_LEN  30   // 5 x MAC(6)
#define MOUNT_ROUTE_PAYLOAD_LEN   5   // one byte per cam
```

Raise `NUM_MOUNTS` to 10 and these stay at 30 and 5. The hub sends a 60-byte
table, the app reads 30, and mounts 6-10 vanish silently with no compile error.
The protocol check will not catch it — it compares declared constants, not
literals at call sites, which is a known blind spot. Make them
`(NUM_MOUNTS * 6)` and `NUM_MOUNTS`, and add a test that asserts they track.

**Every node flashes together.** `NUM_MOUNTS` appears 114 times in the hub, 9 in
the satellite, and in both Python modules. A hub on 10 talking to mounts on 5
misparses every table. There is no staged rollout of that step — hub, all
satellites, all mounts, the display and the app, in one session.

## The split that makes it affordable

Keeping the interfaces five-wide is what turns this from a rewrite into an
indirection.

```
DATA LAYER      grows to N. Hub tracks, routes, polls and recovers all N.
                Arrays, loops, payload lengths. Mechanical.

PRESENTATION    stays five-wide and gains a map: slot 1..5 -> mount id.
                Tabs, joystick bindings, display panels resolve through a
                lookup instead of using the index directly.
```

`main_window.py` alone has `range(1, 6)` scattered through tab construction,
per-mount state dicts, look-at subject tracking and arrow state. Those become
`for slot in visible_slots()` returning mount ids. That is the bulk of the work
and it is mostly mechanical once the map exists.

## The right model is a composable panel, not a view filter

Each control surface is an independent five-mount panel, and you add surfaces to
get capacity. PC app and hub display side by side gives ten mounts at one
position; add the web app on an iPad and it is fifteen.

That is a better model than "choose which five to show", and it simplifies
things: surfaces never need to agree, so there is nothing to coordinate, nothing
to push and nothing to reconcile.

It has one consequence worth acting on early. **Do not bake 5 in as a new
constant.** Once the slot-to-mount indirection exists, panel width is a property
of the surface, not of the rig — a PC app on a wide screen could run eight where
the hub's 7-inch panel runs five or four. Writing `PANEL_SLOTS` per surface costs
nothing now; discovering later that 5 is welded into three UIs costs what this
whole exercise is trying to avoid.

## Fewer than five, too — and it is the same change

A panel shows however many mounts are assigned to it: one, two, three, four or
five. Nothing is drawn for the rest. No cam buttons across the top for mounts
that do not exist, no empty location boxes in the position grid, no dead rows in
the config screens.

This matters beyond neatness. The repository is public and someone building one
or two of these mounts should not open the app to five tabs with four of them
dead. That is the first impression the project makes.

**It is not extra work — it is the same work.** Both requirements reduce to the
same thing:

```
today        for mid in range(1, 6):
after        for mid in self._panel_mounts:
```

"Which five of ten" and "only show two" are both "iterate a list of mount ids
instead of a fixed range". Doing one gets the other free.

The scope, measured:

```
pc_app/ui/widgets/position_grid.py   16 sites   the mount location boxes
pc_app/ui/main_window.py             12         cam buttons, per-mount state
pc_app/ui/dialogs/config_dialog.py    8
pc_app/motion/command_dispatcher.py   2
four other files                      4
                                     42 total
```

### Sequence it in two halves

Land the indirection with the list fixed at `[1,2,3,4,5]`, confirm nothing on
screen has changed, and only then allow shorter lists. The first half is a large
mechanical edit whose correctness is easy to check precisely because nothing
should look different; the second half is small and its effect is obvious.

### Defaults, so a small rig needs no configuration

- **Fresh install, nothing configured:** populate the panel from whatever mounts
  the hub reports as bound, up to the surface maximum. Someone with one mount
  opens the app and sees one mount.
- **A new mount is bound while the panel has room:** add it. Otherwise a user
  pairs their second mount and nothing appears, which looks like a fault.
- **Nothing bound at all:** an explicit empty state pointing at the mounts
  screen. Not a blank grid — a blank grid is indistinguishable from a broken one.

Once a panel is full, or once the operator has deliberately curated it, the
auto-add stops applying and the list is theirs.

## The visible map is PER CLIENT

The deployment is two rooms. A PC app in the concert hall shows five mounts; a
second PC app in the foyer next door shows five different ones; and either can
reach the other's cameras when needed.

That makes the map a property of the client, not of the rig. Each app stores its
own, and the hub does not need to know or care.

**An earlier draft of this note argued the opposite** — that the map had to be
rig-wide, on the grounds that a joystick binds to a slot and two screens
disagreeing about slot 2 would move the wrong camera. That reasoning assumed one
control surface shared between screens. It is not: each PC app has its own
joystick, so "slot 2" resolves inside the app the stick is plugged into and is
never ambiguous. The argument was for a deployment that does not exist.

So:

```
PC app          map in local config, per install. Survives restart. Hub uninvolved.
Web app         map in browser storage, per device.
Hub display     its own map, stored in hub NVS — see below.
```

No new protocol commands are needed for any of this, which also removes the
persistence and push machinery the rig-wide version would have required.

### The hub display is the exception

It is a single physical panel with its own touch controls, so "per client" means
"the one there is". Its map belongs in hub NVS because that is where the display's
other settings live — but it is the display's map, not the rig's, and nothing
else should read it.

It is also the surface most likely to surprise someone: an operator in the
concert hall has no way to see what the panel by the rack is showing, or that
somebody is standing at it.

## Concurrent control, which the two-room setup makes real

Cross-control is the requirement, so this needs stating plainly: **there is no
arbitration today, and there never has been.**

```
MAX_CLIENTS   4 TCP slots, plus WebSocket, plus serial, plus the display, plus OSC
ownership     none
arbitration   none — last command wins
notification  none — no client is told another has taken a mount
```

`_last_client_cmd_ms` exists but is rig-wide and only defers the maintenance
restart. Nothing records which client last commanded which mount.

With one operator this never bites. With two rooms and deliberate cross-control
it will: the foyer operator takes cam3 for a shot, the concert hall operator jogs
the same camera a second later, and neither screen shows the other.

**The fix is visibility, not locking.** In live production an operator must be
able to take a camera immediately — a lock that has to be released by someone in
another room is worse than the collision it prevents. What is missing is that
nobody can *see* the collision.

The minimum useful version: the hub records which client last commanded each
mount and when, and pushes it with the rest of the mount state. A UI can then
show "cam3 — driven from Foyer, 2 s ago" and the operator decides. That is a
per-mount client id and timestamp, a few bytes, and no behaviour change to the
control path at all.

Worth building alongside the multi-mount work rather than after it, because
cross-control is one of the reasons for doing it.

## Build order

Each step ships on its own and is testable before the next.

**1. Derive the payload lengths, at NUM_MOUNTS = 5.** No behaviour change, no
visible difference, flashes normally. De-risks everything after it.

**2. Introduce the panel list, still at 5.** The list is `[1,2,3,4,5]`, so
nothing changes on screen. All three UIs stop iterating a fixed range and start
iterating the list — 42 sites in the PC app alone. The largest code change, and
it lands while the rig behaves exactly as it does today, which is what makes it
checkable.

**2b. Allow the list to be shorter.** Small change, obvious effect, and it ships
a real benefit on its own: anyone with one or two mounts gets an app that fits
their rig, whether or not the rest of this is ever built. Worth having even if
ten mounts never happens.

**3. Raise NUM_MOUNTS to 10.** The whole-rig flash. Ten slots exist; only five
can be filled until step 4, which is a usable intermediate state rather than a
broken one.

**4. The pickers**, in whatever order suits:

- **AMOLED** — replace `_setup_id_btn[5]` on the SETUP screen with a numeric pad
  and an OK, modelled on the camera-pairing screen. Five fixed buttons do not
  extend; a pad does, and it is the only way to assign an id above 5.
- **PC app** — a mounts screen listing mounts 1..N top to bottom, each row
  carrying its visible-slot assignment. See the note on touch below.
- **Hub display** — the same list, scrollable, since ten rows will not fit the
  7-inch panel at the current row height.
- **Web app** — the same again. It is a single 144 KB header, so this is the
  most self-contained of the three.

## On the touch input for slot assignment

A conventional dropdown is a poor touch target and worse on the hub's panel: it
opens a list that can fall off-screen, needs a second accurate tap, and gives no
feedback about what is already assigned elsewhere.

Better for this specific case — six choices, mutually exclusive, and the operator
needs to see conflicts:

**A row of six buttons per mount: `—  1  2  3  4  5`.** One tap, no second
target, current state visible without opening anything, and a slot already taken
by another mount can be shown greyed or struck through. It also makes the
constraint self-evident: five slots, N mounts, so most rows will read `—`.

This is the same pattern the AMOLED setup screen already uses for CAM 1-5, so it
is consistent with what exists rather than a new idiom.

## Open questions worth settling early

**Does an unselected mount stay live?** It should. Keep polling, keep health,
keep the recovery ladders running. Making visibility a comms filter would mean a
mount you cannot see is a mount you cannot diagnose, and every fault this rig has
had was found by continuous reporting from a node nobody was looking at.

**What happens when a visible mount goes offline?** Leave the slot assigned and
show it offline, rather than auto-reassigning. Auto-reassignment moves cameras
under the operator's hands.

**RAM on the hub.** Per-mount state doubles. The hub runs at ~165 KB free, and
the per-mount structures are small, but this should be measured at NUM_MOUNTS=10
before the flash rather than assumed.

**Satellite distribution.** With ten mounts the 20-peer ceiling is not binding,
but the RF geometry might be: the reverse path is what governs delivery, and
adding five mounts to one hub radio concentrates that. Worth deciding which
mounts sit behind which satellite by signal rather than by convenience — see
2026-09-16-ble-baseline.md for why the reverse path is the number that matters.

**A coordinator hub with no ESP-NOW at all**, with every mount reached through
satellites. Held in reserve, not recommended now.

The argument for it is fault isolation, not congestion — congestion was
considered and does not hold, since Foyer wedges at a 1 ms loop time and the
mounts wedge too. #18682 leaks a buffer roughly once in 2,400 sends regardless of
how busy a node is, so removing the hub's radio relocates the fault rather than
removing it. What it would buy is that **the hub never needs to reboot for a
radio fault**, and today a hub reboot takes the PC app link, the display, OSC and
the web UI with it.

Against it, and why it waits:

- The NO_MEM rung already turns that 2 h 40 m outage into about 25 seconds
  without anyone present. Re-architecting around a failure that now has a
  25-second automatic recovery is a lot of hardware for a marginal gain.
- It concentrates every mount on the satellites, and Foyer has the worst history
  on the rig — eight self-restarts in 54 hours before the 15 September flash.
  Basement is pristine but currently relays nothing.
- It conflicts with the small-build case above: one or two mounts would need a
  hub *and* a satellite where the hub alone does it today. Direct attach should
  stay supported whatever this rig ends up doing.

**The trigger that would justify it:** the hub refusing sends again despite cap 1
and the rung — particularly if the rung fires and does not clear it. At that
point "the hub must never reboot for a radio fault" stops being tidiness and
becomes the fix.

It can be tested for nothing before it is built, but **not yet**. Binding every
mount to a satellite makes the hub ESP-NOW-silent with no code change at all —
`send_to_mount_routed()` returns after the TCP write and never reaches
`espnow_send_if_present()`. That is a free experiment, and it would also confound
the one currently running, which is whether cap 1 and the rungs work. Let those
report first.

## Load, measured, because the TX path was only just stabilised

A satellite relaying two mounts is offered **62 frames per 10 s**, so roughly
**3.1 frames/s per mount** of steady keepalive and polling. Fifteen mounts is
therefore about 47 frames/s — if they all hang off one radio.

Against that, the in-flight cap is 1 and the bench measured a full 32-deep queue
draining in 30-90 ms, so around 1-3 ms per callback: several hundred sends per
second of capacity. 47/s is a comfortable fraction of it.

So the arithmetic is fine, but it is a threefold increase on a transmit path that
spent a week wedging and has only been quiet since 13 September. Two things
follow:

- **Measure rather than assume.** `sends held back per 10 s` on the hub and
  `offered / sent / refused` on each satellite are the numbers that would show
  the cap starting to bind. They are already in every health line.
- **Distribute across satellites rather than concentrating on the hub.** Five
  direct plus ten relayed puts only five mounts' worth of ESP-NOW on the hub's
  own radio, and the 20-peer ceiling points the same way. Hanging fifteen off the
  hub would work on paper and would make the hub the single point that has
  historically been the one to fail.

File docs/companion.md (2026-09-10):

# Bitfocus Companion (and QLab) control

**The hub is the OSC server.** One server, on the hub, UDP port **9700** —
`192.168.4.1` on the hub's `PTS-` AP, reachable from the LAN through a WiFi→LAN
bridge joined to that AP, or from any machine joined to it directly. No
PC needed: hub + display + mounts + Stream Deck is a complete rig.

There used to be a second server inside the PC app on the same port and the
same `/pts/...` namespace, and the two had drifted apart — `tally` and `record`
existed only in the PC app, `autofocus` and `zoom` only in the hub. A tally
button aimed at the hub was a perfectly good message arriving at a server that
had never heard of tally, and unknown addresses are dropped in silence. The PC
app's server is gone; every address below is the hub's.

The practical consequence: the hub is always on and a laptop is not, so a tally
lamp or a record cue no longer depends on anyone's PC app being open.

## Companion connection

1. Companion → **Connections** → add **Generic: OSC**
2. **Target IP** = the hub (`192.168.4.1` on its `PTS-` AP) ·
   **Target port** = `9700`
3. Use the connection's **"Send message"** actions on buttons as below.
   Argument type matters: use **integer** arguments (floats also accepted).

## Address reference

| Address | Args | Action |
|---|---|---|
| `/pts/estop` | – | E-STOP **all** mounts |
| `/pts/cam/N/estop` | – | E-STOP mount N |
| `/pts/cam/N/goto` | slot `1-10` | Recall stored position (uses active speed presets) |
| `/pts/cam/N/store` | slot `1-10` | Store current position |
| `/pts/cam/N/clear` | slot `1-10` | Clear a stored position |
| `/pts/cam/N/jog` | pan tilt slider zoom (`-1000..1000`) | Start/refresh a jog — server re-streams at 20 Hz |
| `/pts/cam/N/jog/stop` | – | Stop jogging |
| `/pts/cam/N/jog/left` | `1` press / `0` release | Pan left |
| `/pts/cam/N/jog/right` | `1` / `0` | Pan right |
| `/pts/cam/N/jog/up` | `1` / `0` | Tilt up |
| `/pts/cam/N/jog/down` | `1` / `0` | Tilt down |
| `/pts/cam/N/jog/slide/left`  | `1` / `0` | Slide left |
| `/pts/cam/N/jog/slide/right` | `1` / `0` | Slide right |
| `/pts/cam/N/jog/zoom/in` | `1` / `0` | Zoom in |
| `/pts/cam/N/jog/zoom/out` | `1` / `0` | Zoom out |
| `/pts/cam/N/speed/pt` | `1-4` | Active pan/tilt speed preset |
| `/pts/cam/N/speed/sl` | `1-4` | Active slider speed preset |
| `/pts/cam/N/speed/pt/up` | – | Pan/tilt speed one step faster (clamped at 4) |
| `/pts/cam/N/speed/pt/down` | – | Pan/tilt speed one step slower (clamped at 1) |
| `/pts/cam/N/speed/sl/up` | – | Slider speed one step faster |
| `/pts/cam/N/speed/sl/down` | – | Slider speed one step slower |
| `/pts/cam/N/speed/pt/inc`  | – | Pan/tilt speed 1→2→3→4→1 (wraps) |
| `/pts/cam/N/speed/sl/inc`  | – | Slider speed 1→2→3→4→1 (wraps) |
| `/pts/cam/N/subject` | `0-7` | Select look-at subject (switches live mid-move) |
| `/pts/cam/N/lookat` | `0` (◀ min) / `1` (▶ max) | Look-at slider move with the selected subject |
| `/pts/cam/N/autofocus` | – | Instantaneous autofocus on that mount's Blackmagic camera |
| `/pts/cam/N/tally` | `0`/`1`, or `0.0-1.0` | Tally lamp **brightness**, both lamps |
| `/pts/cam/N/tally/front` | `0`/`1`, or `0.0-1.0` | Front lamp only (facing talent) |
| `/pts/cam/N/tally/rear`  | `0`/`1`, or `0.0-1.0` | Rear lamp only (facing operator) |
| `/pts/cam/N/record` | `0` stop / `1` start | Start or stop recording on that camera |
| `/pts/cam/N/record/toggle` | – | Start if stopped, stop if rolling — reads the camera's reported transport, not the last command |
| `/pts/refresh` | – | Resend all feedback for every mount |
| `/pts/cam/N/refresh` | – | Resend all feedback for mount N |

`N` = camera 1-5.  Slots and speed presets are 1-based, subjects 0-based —
matching what every screen in the system shows.

## Button recipes

**Recall shot 3 on camera 2** — the bread-and-butter Stream Deck button:
- Press actions: `Send message` → `/pts/cam/2/goto`, int arg `3`

**Hold-to-jog pan-left on camera 1** (uses Companion's press *and* release
action lists):
- Press actions:   `/pts/cam/1/jog`, ints `-400 0 0 0`
- Release actions: `/pts/cam/1/jog/stop`

**Look-at: track subject 2, slider to the right, camera 3**:
- Button A press: `/pts/cam/3/subject`, int `2`
- Button B press: `/pts/cam/3/lookat`,  int `1`
  (pressing Button A during the move switches the tracked subject live)

**Speed page** — four buttons per camera: `/pts/cam/N/speed/pt` with `1..4`.

**Record with a tally that tells the truth** — two halves of one button:
- Press action: `Send message` → `/pts/cam/5/record/toggle`
- Feedback: OSC value of `/pts/cam/5/recording` → `1` lights the button

The button lights from the camera's transport report, not from the press, so a
press that did not take — no card in the camera, Bluetooth dropped — leaves it
dark rather than lying about it.

**Tally lamp** — `/pts/cam/N/tally` with int `1` for full and `0` for off, or a
float for anything between.

> **The Pocket Cinema Camera 4K ignores this.** Tested on the rig on
> 2026-08-17: three tally commands reached a paired, actively reporting camera
> and it neither answered nor changed. On connect that camera volunteers
> categories 0, 1, 3, 4, 9, 10 and 12 — ISO, white balance, shutter angle,
> battery, transport, lens type, reel, take, operator — and has never once
> mentioned the tally category. A body that describes itself that thoroughly
> would report tally if it had it.
>
> The address is kept because it is correct by the published spec and a studio
> or URSA body — which is what the tally group is aimed at — should accept it.
> **On a Pocket, the thing that lights the front indicator is the camera
> recording.** So the tally you can actually drive is `/pts/cam/N/record`, and
> `/pts/cam/N/recording` coming back is the camera confirming it.

### Direction buttons

The named `jog` directions exist for button surfaces; `/pts/cam/N/jog` with its
four signed values is still there for a stick or a fader.

Bind **press → `1`** and **release → `0`** on the same address.  Any non-zero
value is full deflection — a button sends `1`, and honouring that as a
magnitude would creep the mount rather than move it.  Speed comes from the
active preset, not from the argument.

Each direction owns one axis and leaves the others alone, so holding *left* and
*up* together gives a diagonal, and releasing one leaves the other running.

If a release is lost, the 15 s TTL stops the jog anyway, and the mount's own
500 ms dead-man stops it if the hub goes away entirely.

Speed `up`/`down` need no argument and clamp at 1 and 4, so one button can walk
the preset without Companion tracking which one is active, and a button held at
either end is inert rather than wrapping round mid-shot.

`inc` wraps instead — 1→2→3→4→1 — which is what the web app and the PC app do
from a single control.  Use `inc` for one button that cycles, `up`/`down` for a
pair that cannot overshoot.

**Show-stopper**: a big red `/pts/estop` (no argument needed).

## QLab

QLab network cues speak OSC natively, so camera moves can be *cues in the
show script*: patch a network destination to the PC's IP port `9700`, then a
cue like `/pts/cam/2/goto 4` fires a camera recall in the cue stack, exactly
in time with lighting and sound.  (QLab sends numbers as floats — the server
accepts that.)

## Feedback (hub → Companion)

The hub replies to **whoever last sent it a command** — no configuration at
either end, and a second surface starts receiving as soon as it takes over.
Messages go to that sender's IP and source port; if your controller transmits
from an ephemeral port and listens on a fixed one, set `OSC_REPLY_PORT` in
`esp32_hub_eth.ino` to that number.

All arguments are a single int.

| Address | Value | Meaning |
|---|---|---|
| `/pts/cam/N/active` | 0/1 | Mount is online (STATUS seen recently) |
| `/pts/cam/N/state` | int | Mount state — 0 IDLE, others per `MountState` |
| `/pts/cam/N/target` | 0-10  | Slot being moved to, 0 = not moving to one |
| `/pts/cam/N/speed/pt` | 0-4 | Active pan/tilt speed preset — **0 = this mount is not there** |
| `/pts/cam/N/speed/sl` | 0-4 | Active slider speed preset — **0 = no rail, or mount not there** |
| `/pts/cam/N/slot/M/state` | 0-3 | Slot M — see below |
| `/pts/cam/N/recording` | 0/1 | That camera is **rolling** — see below |
| `/pts/cam/N/lookat/mode` | 0/1 | 1 = look-at mode — **buttons 9 and 10 are the ◀/▶ rail ends, not slots** |
| `/pts/cam/N/lookat/subject` | -1..7 | Subject currently being tracked, -1 = none |
| `/pts/cam/N/calib/prompt` | 0-6 | Calibration step in progress — see below |

`/pts/cam/N/recording` is the camera's own account of its transport mode, not
an echo of the record command. Blackmagic never acknowledges a command, so a
record cue that failed — no media in the camera, Bluetooth dropped — produces
nothing here and the button stays dark. A lit button is a camera that is
actually recording.

It reads 0 until the camera reports otherwise, which is also what it reads when
no camera is paired to that mount.

### Look-at

`/pts/cam/N/lookat/mode` is the one to build a page around. It decides what
buttons 9 and 10 **mean** — two more stored positions, or the two ends of the
rail. A page that assumes one or the other goes wrong the moment the mode is
changed from the PC app, the web app or the hub display, so drive the button
labels from this rather than setting them by hand.

With it at 1, slots 9 and 10 report the arrows through the ordinary slot
addresses: `2` (AT) when the slider is parked at that end, `3` (MOVING) while
it is travelling there, `0` otherwise. Slots 1-8 report `1` (OCCUPIED) for each
subject that has been calibrated.

`/pts/cam/N/lookat/subject` is the one being tracked right now — the green
border on every other client. The slot addresses say which subjects exist; this
says which is live.

`/pts/cam/N/calib/prompt` follows a subject calibration:

| Value | Meaning |
|---|---|
| `0` | nothing in progress |
| `1` | moving the slider to the home end |
| `2` | at home — aim the camera, then Set A |
| `3` | moving the slider to the far end |
| `4` | at the far end — re-aim at the same subject, then Set B |
| `5` | solved and stored |
| `6` | failed — the two observations were too alike |

Calibration cannot yet be *started* from Companion; there is no OSC command for
it. This publishes the prompt so a Deck can show where a calibration driven
from another client has got to — useful when the person aiming the camera is
not the person at the PC. `5` and `6` clear themselves back to `0` after eight
seconds, so a button shows the outcome and then goes quiet.

Slot state is one address per slot carrying one value:

| Value | Meaning |
|---|---|
| 0 | empty — nothing stored here |
| 1 | occupied — stored, mount elsewhere |
| 2 | moving — mount is on its way here |
| 3 | at — mount is here |

A button binds to that single address and picks its colour from the value, with
no bitwise expression and nothing to combine.  It is the same picture the
display and the web app show — stored, moving-to, arrived — and because it
arrives as one message it can never be seen half-updated.

Only changes are sent, so a rig at rest is silent.  Everything is resent every
5 s regardless, so a surface that joins late — or misses a UDP packet — catches
up on its own without having to ask.  The first message from an address the hub
has not heard from also triggers a full send.

A mount with no slider reports `speed/sl` as **0**, which no preset ever uses,
so a button can hide or grey itself instead of showing a speed for an axis that
cannot move.  The hub also ignores `speed/sl/...` and `jog/slide/...` for those
mounts, so a button pressed against a rail-less mount does nothing rather than
walking a number that controls nothing.  This matches the web app, which has
always zeroed the slider axis for a mount without one.

### Camera control

`/pts/cam/N/autofocus` triggers instantaneous autofocus on the Blackmagic camera
attached to that mount, over the mount's own Bluetooth link — no SDI cable and
no converter.

It is fire-and-forget: the Blackmagic protocol has no acknowledgement, so
nothing comes back to say the lens moved.  If a camera is off, asleep or not
paired, the command is simply dropped at the mount.  Whether a mount's camera
link is up shows in the PC app's **CC** panel and in `comms.log` as
`BLE PAIRED`.

**Each mount must be paired with its camera once, on a bench.**  Every mount
ships with camera control built in, but Bluetooth pairing needs the six-digit
code the camera puts on screen, typed in while someone is watching — so it
cannot happen out on a rig.  The bond is then stored on the mount and survives
power cycles and reflashes.

The bond is also how a mount knows which camera is *its own*.  With several
cameras on a rig they all advertise the same way, so an unpaired mount has
nothing but signal strength to go on and can reach for a neighbour's camera;
a paired one goes straight to the camera it was paired with and ignores the
rest.  A mount that has never been paired says so
specifically, in the **CC** panel as *not paired* and in `comms.log` as
`BLE NOT PAIRED` — distinct from *camera off*, because the fix is different.

To pair, hold the mount's screen to reach SETUP, then hold again for CAMERA
PAIRING.  The camera shows six digits; type them on the keypad.  **FORGET**
clears every camera this mount is bonded to, which is what a camera moved to a
different mount needs.  The mount is off the air while pairing, so the screen
leaves on its own after two minutes.

`/pts/refresh` asks for that full send on demand.  Bind it to a Companion
startup trigger, or to a button, for the case the automatic paths do not cover:
a Companion that restarts on the same port is not a new peer, so without asking
it would show stale buttons until the next 5 s resend.

### A mount that is off

A mount the hub has not heard from for 16 seconds reads as inactive, and every
one of its slots then reports `0` (empty) — the same as a slot with nothing
stored.  `/pts/cam/N/active` says `0` alongside, so a page that wants to grey
the whole camera rather than just unlight its buttons can.

Both speed presets read `0` for the same mount, and a speed button pressed at
it does nothing — not even to the reported number.  The hub cannot pass the
command on, so accepting it would walk its own copy of a preset the mount was
never told about, and the desk would show that walked number the moment the
mount came back.

The point is that a powered-off mount stops advertising anything a desk can
act on: no locations to recall, no speed to step.  Its stored positions and
presets survive in the mount's own memory and come back when it does; what
goes away is the desk claiming they are there to press.

### After the hub restarts

The hub learns where to send feedback from the source address of whatever a
surface sends it, so it has nowhere to send until spoken to.  That address is
now remembered across a restart, and a remembered peer gets the same full send
a newly-met one does — so the desk is brought up to date on its own rather than
holding whatever it last received.

If the desk has moved to a different address in the meantime, the remembered
one costs a few UDP packets into nothing and is corrected the moment the real
one talks.

## Safety notes

- Jogs started over OSC are re-streamed at 20 Hz by whichever server received
  them (the mount's own 500 ms dead-man requires a live stream).  If the
  *release* message is lost (UDP), a **15 s TTL** stops the jog anyway — for
  long moves prefer `goto` / `lookat`, which are position-bounded.
- The mount-side dead-man still applies end-to-end: if the hub or PC app dies
  mid-jog, motion stops within 500 ms regardless of Companion.
- E-STOP over OSC also cancels any OSC-held jog streams immediately.
- Hub-side extras: OSC jogs engage the same radio-contention protection as
  web-app jogs, OSC `lookat` triggers the ◀/▶ arrow flash on every connected
  UI, and Companion activity defers the hub's idle maintenance restart.

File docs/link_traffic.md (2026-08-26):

# What travels between a mount and the hub

**There are two links, and they carry very different amounts.** Almost every
question about traffic on this rig resolves once that distinction is clear:

```
Teensy  ⇄  AMOLED bridge  ⇄  [satellite relay]  ⇄  hub  ⇄  PC app / web app / display
        UART                ESP-NOW
      115200 baud            radio
     private wire          contended
```

The Teensy talks to the AMOLED board over a dedicated serial wire. That board —
`esp_mount_amoled175`, which is the mount display *and* the ESP-NOW bridge —
decides what is worth putting on the air. **The high rates all live on the
UART. The radio sees almost none of them.**

That filter is the single most important thing in this document. Reading the
Teensy's send rates and assuming they are radio rates overstates the traffic by
more than an order of magnitude.

---

## Link 1 — Teensy ⇄ bridge (UART, on the mount)

Not radio. A private wire to one peer, so rate here is cheap.

| Mount → bridge | Rate | Payload |
|---|---|---|
| `STATUS` | **100 ms** (10 Hz) | 10 B |
| `POSITION` | **on request only** — nothing sends `GET_POSITION` today | 17 B |
| `HEALTH` | 10 s | — |
| `LOOK_AT_STATUS` | on change only | 14 B |
| `CONFIG_REPORT` | on request | 77 B |
| `STATE_REPORT` | on request | 182 B |
| `SUBJECT_LIST` | on request / after a calibration | 232 B |
| `CALIB_PROMPT`, `LIMITS_FOUND`, `HOME_COMPLETE`, `REF_CONFIRMED`, `ACK`, `NACK` | one-off events | small |

Framing costs 9 bytes on top of every payload.

## Link 2 — bridge ⇄ hub (ESP-NOW)

The contended link, and the one that matters.
`teensy_frame_worth_sending()` in the bridge is where the rates above become
these — it can be disabled wholesale with `TEENSY_FWD_FILTER`, which is worth
knowing exists before concluding the radio is quiet.

### Uplink (mount → hub)

| Packet | What actually goes out |
|---|---|
| `STATUS` | **on change**, otherwise a 5 s refresh (`MOUNT_STATUS_REFRESH_MS`) |
| `LOOK_AT_STATUS` | on `subject_id`/`flags` change, otherwise 5 s — the three floats beside them are deliberately excluded from the comparison, because they change every frame and nothing reads them |
| `POSITION` | **only within 2 s of a `GET_POSITION`** (`POS_ON_DEMAND_MS`). The unsolicited 5 Hz stream is dropped at the bridge and never reaches the air |
| `HEALTH` | 10 s, deferred while a jog is being forwarded |
| everything else | forwarded as-is — each is a one-off notice of something that happened, and the only notice of it |

### Downlink (hub / clients → mount)

| From | Packet | Rate |
|---|---|---|
| Hub | `PING` broadcast, 4 B timestamp | **2 s** (`BASE_HEARTBEAT_MS`) |
| PC app | `PING` broadcast | **1 s** |
| PC app | `GET_CONFIG` idle probe, per connected mount | after 3 s with no ack-tracked send |
| PC app | `GET_SUBJECTS`, look-at mounts | ~4 s |
| PC app | `GET_POSITION` | nothing sends one — see below |
| any client | `JOG` | **streamed while a stick is held** — the heaviest thing on the link |
| any client | `MOVE_REL`, `GOTO`, `SET_*`, `GET_*` | user-driven |

---

## The shape of it

**At rest, a mount costs about one packet every 5 seconds upward and a 2 second
ping down.** Nothing on the radio link is 10 Hz.

Two things dominate when they happen, and both are worth knowing before adding
anything periodic:

- **Jog streaming.** Held sticks produce continuous packets. This is real work
  and cannot be filtered — the mount must hear every one to move smoothly.
- **The position stream, if ungated.** 5 Hz per moving mount is what
  `POS_ON_DEMAND_MS` exists to prevent.

Traffic here is not a theoretical concern. An ESP-NOW TX wedge on this rig is
rate-dependent: cutting satellite traffic by 88% took one satellite from 36
restarts in 17 hours to zero.

## Before adding anything periodic

Two questions, in this order.

**1. Is it already carried?** `STATUS` goes out on every change and carries
state, flags, both speed presets, both slot masks, the target slot and the
active look-at subject. A new periodic packet duplicating any of that is a
second stream saying what the first already said.

**2. Is it the liveness signal?** Both the hub and the PC app refresh presence
on **any** packet from a mount, not on a particular command, and `STATUS` is
never gated by state. So removing a periodic packet does not usually change how
quickly a dead mount is noticed — but check, because if the thing being removed
*were* the only traffic during some state, a mount would appear dead the moment
it entered that state. That fault would only ever show up mid-event.

## Filter at the source, not downstream

The bridge filter is a safety net, not a licence. `LOOK_AT_STATUS` was broadcast
by the Teensy at 10 Hz for the whole of a look-at move while the bridge quietly
discarded almost all of it — correct on the air, wasteful on the wire and in
bridge CPU, and misleading to anyone reading the Teensy source to work out what
the rig transmits.

---

## Positions are answered, never volunteered

`CMD_POSITION` is sent only in reply to a `CMD_GET_POSITION`, and **nothing
sends one today**. So there is no position data anywhere in the system unless
something is added that asks for it.

It was not always so, and the history is a good illustration of how a stream
outlives its readers:

| | |
|---|---|
| 30 Jul | Teensy broadcast `POSITION` at 5 Hz moving / 1 Hz at rest. The PC app's Config tab showed it live. |
| 12 Aug | The bridge began gating it on a recent `GET_POSITION` — "stop putting telemetry on the air that nothing reads". The Config readout went blank, and nobody noticed. |
| 19 Aug | A zoom diagnostic polled `GET_POSITION`, which revived the readout and the position log by accident. |
| 21 Aug | The diagnostic was removed, both went quiet again, and the dead Config readout was deleted. |
| 21 Aug | The unsolicited broadcast was removed at the Teensy, since the bridge had been discarding it for nine days. |

A third diagnostic came and went the same way in August: a 5 Hz poll during
look-at moves, added because two attempts to fix an abrupt subject switch had
been reasoned from the firmware rather than measured. It found the cause in one
run — the camera pinned against a speed cap at half the peak the easing curve
asked for — and was removed once the profile came back a bell.

**Two consumers are dormant, not broken.** `comms/position_log.py` still
subscribes and would log travel and overshoot the moment positions flowed —
it is what measured the rail geometry — and anything else can subscribe the
same way. Reviving either means sending `GET_POSITION`, which is deliberately
the visible act: whatever wants positions has to ask, and shows up in the log
as the thing that opened the tap. An unsolicited stream is a producer nobody is
accountable for.

Two diagnostics that once used it have been removed, both having answered the
question they were added for:

- **`ZOOM_DIAGNOSTIC`** (PC app) — added when zoom on mount 5 crept away from
  stored positions and sprang back when the slot was pressed again. It turned on
  `GET_POSITION` polling, zoom travel logging, and naming OSC-driven jogs so
  surface-driven motion could be told from joystick motion. The creep turned out
  to be a stranded goto axis; the movement that started the hunt turned out to be
  OSC commands, which never reach the PC app at all — which is why three rounds
  of PC-app instrumentation could not see them. Removed in "remove both
  temporary diagnostics".

- **`GOTO_DEBUG`** (Teensy → clients) — had the mount report what its goto
  planner decided the moment it decided it. It is what proved the stranded axis:
  the plan said 399 ms and the moving mask still showed that axis turning three
  seconds later. Removed with the same commit.

If either is ever needed again, the shape to copy is this: report what the
firmware DECIDED, not just what it did. Position samples alone could not
distinguish an axis overshooting from an axis being commanded somewhere new.

- **`LOOK_AT_DIAGNOSTIC`** (PC app only) — asked each tracking mount for its
  position at 5 Hz and logged pan and tilt with the velocity between samples,
  a summary of the whole switch on one line, and whether the tilt reversed.
  It is what settled the subject-switch work of 2026-08-26 after three fixes
  reasoned from the firmware had changed nothing an operator could see. It
  found: the plateau was the axis pinned at TeensyStep4's `vMaxMax`; the ease
  out was 15–19 ms, less than one control tick; and the tilt arced on every
  switch. Removed once the motion was right.

  It lives complete at **`bd1604f`**, with its own test:

  ```
  git show bd1604f:tools/test_look_at_motion_probe.py
  git show bd1604f:pc_app/comms/mount_manager.py
  ```

  Two things in it cost a measurement round each and are worth keeping if it
  comes back. Time each sample by when the REQUEST went out, never by when the
  reply arrived — transport jitter lands entirely in dt while the position
  delta stays honest, and every "spike" in the early logs was that, not the
  mount. And score the motion against the curve it is meant to be following
  (`6 × travel / duration²`) rather than reporting where the biggest velocity
  step fell: a smoothstep peaks in acceleration at both ends, so once the shape
  is right, "biggest step at the ease out" is the curve, not a fault.

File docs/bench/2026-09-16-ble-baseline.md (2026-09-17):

# What a paired camera actually costs: 18 KB of heap, and nothing else

Rewritten 2026-09-17. The first version of this file recorded a baseline and
proposed an experiment to find out whether BLE degrades the ESP-NOW link. The
experiment ran the same day and the answer is no — the two mounts that appeared
to show it were both suffering antenna obstruction, and both were fixed by hand
in under an hour.

The original version is in the history if the reasoning is wanted. What follows
is what is actually true.

## The finding

```
                min heap    camera
cam1              8198k     none
cam2              8196k     none
cam3              8197k     none
cam4              8180k     PAIRED      (8199k before pairing)
cam5              8180k     PAIRED
```

Pairing a Blackmagic camera costs **about 18 KB of heap**, permanently, and that
is the whole measurable cost. cam4 dropped 8199k → 8180k within minutes of
pairing and landed on cam5's figure to the kilobyte. Three cameraless mounts sit
at 8196–8198k.

With ~8.2 MB free on these boards it is not a constraint. It is worth knowing
only because it is real, repeatable and instant — which made it easy to mistake
for the start of something worse.

## What it does NOT cost

Nothing measurable in the radio. After both antennas were corrected, with
cameras still paired and reporting:

```
cam4   txfail frozen at 151 for 2.5 h   — not one failed send since
cam5   txfail frozen at 111 for 2.25 h  — not one failed send since
cam1/2/3 (no camera) continued their usual trickle over 31.8 h
```

The two mounts with cameras are currently the cleanest on the rig.

## The two false positives, because they are the useful part

Both mounts looked like clear evidence that BLE degrades the link. Both were
antenna obstruction.

**cam4.** Paired at 10:45, and within three hours its failure rate went from
2.9/h — over a clean 22.5-hour baseline — to 43/h. Its RSSI had also moved
−64 → −71 dBm, which was noted as a confound and then argued around. A cable had
been laid near the antenna while fitting the camera. Moving it restored −64 dBm
and the failure count stopped dead.

**cam5.** Running 20–29/h for days at a comfortable −50 dBm, which is why RF had
been discounted: the signal looked fine. It looked fine because the wrong
direction was being measured.

```
          what the mount HEARS     what the relay hears FROM it     gap
cam1          -36 dBm                    -30 to -29                  +6
cam2          -49                        -57 to -51                  -5
cam3          -49                        -50 to -47                   0
cam4          -64                        -78 to -70                 -10
cam5          -51                        -89 to -79                 -32
```

cam5's antenna had no line of sight to its satellite. It heard the relay at
−51 dBm and the relay heard it at −79 to −89 — around 7 dB above the noise
floor, against cam3's 42 dB. Standing the antenna vertical and clear of
obstructions gained ~5 dB on the forward path and stopped the failures outright.

## The lesson, stated so it discriminates

**`txfail` counts transmissions that were not acknowledged. It is therefore a
question about the RECEIVER, and the sender's own RSSI is the wrong number to
look at.** A mount can report an excellent signal and be nearly inaudible at the
other end; cam5 was 32 dB asymmetric and every instrument on the mount said it
was healthy.

The reverse path is visible in the `mount N ONLINE — rssi=` events, which is what
the hub or satellite heard. That comparison took one query and would have found
both faults immediately.

**But "suspect RF first" is only right for the right symptom**, and it would have
been wrong earlier in this project:

```
txfail CLIMBING steadily          an RF question. Check the reverse path first.
txfail FLAT while sends stop      NOT RF. Nothing on air can freeze a counter
                                  of on-air failures — that is the ESP-NOW
                                  TX wedge, see 2026-09-12-hub-nomem.md.
```

Days went into RF, range and antennas for the wedge before it was ruled out, and
correctly ruled out — a mount ran clean for hours at −80 to −85 dBm. The
distinguishing fact is whether the counter is moving.

## For the remaining cameras

Three more are to be fitted. On this evidence the procedure is short:

1. **Check the antenna has clear air before fitting**, and check nothing has been
   laid across it afterwards. That single step accounts for everything this
   investigation found.
2. **Compare both directions after pairing**, not just the mount's own RSSI — the
   table above is the check, and an asymmetry beyond ~10 dB is worth acting on.
3. **Expect ~18 KB of heap to go** and nothing else. If the failure rate climbs
   and stays climbing with a clear antenna and a symmetric link, that would be
   new and worth reporting.

## One note on how this was found

The logs pointed at BLE twice and were wrong twice. Both causes were found
physically, by inspection, within an hour — after this document had proposed a
multi-day experiment to test the wrong hypothesis. The reverse-path data that
would have settled it was already in the log the whole time and was not being
read.

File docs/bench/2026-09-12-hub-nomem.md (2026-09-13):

# The hub's ESP-NOW transmit wedge is NO_MEM, and nothing could see it

Caught in the act on the rig, 2026-09-12 19:49, after roughly five weeks in which
every occurrence had looked — from every counter that leaves the hub — like
nothing was wrong at all.

This is the write-up for anyone reading their own logs and finding the same
shape: mounts that report health but stop taking commands, while every hub-side
number stays flat.

## The signature

```
14:45 - 17:28    cam1  0/81    cam2  0/80    cam3  0/78      direct
                 cam4  58/58   cam5  167/167 (100%)          via a satellite

19:49 - 21:16    the same, again
```

Three mounts on the hub's own radio take **zero** commands for hours. The two
reached over Ethernet through a satellite run at 100% throughout. The hub keeps
accepting bytes from the PC, keeps relaying, keeps answering its own diagnostics.

Meanwhile, on the hub itself, for the whole of it:

```
txfail       23, flat — not one increment
heap         154-163k, normal
loop         10-20 ms worst pass
leak floor   steady
overflow     0
held back    0
self-rescue  never fired
```

Both episodes ended because a person rebooted the hub. So did the fourteen-hour
outage on 2026-09-08.

## Why every counter lied

`esp_now_send()` was returning `ESP_ERR_ESPNOW_NO_MEM`. **A refused send never
becomes a transmission**, so it cannot appear in a counter of sends that failed
on air — which is exactly what `txfail` is. The frame never reaches the radio,
nothing is outstanding, no callback is owed, and every instrument built to watch
the transmit path reports a healthy one.

The hub's firmware had detected this all along. It printed a line about it:

```
[ESPNOW] send to mount %d REJECTED: %s
```

to `Serial`, on a box that lives in an enclosure. The comment above it read
*"this is the line that would identify the wedge"*. Nobody had ever read it.

## Why the self-rescue ladder stayed silent

Three rungs, and the fault slips between all of them:

| rung | armed by | why it missed |
|---|---|---|
| peer refresh | 4 consecutive send **failures** | a refused send produces none |
| ESP-NOW reinit, WiFi bounce, restart | a run of send **failures** | as above — `txfail` flat at 23 |
| callback-stall clock | sends accepted, nothing returning | the pool is already empty, so nothing is outstanding and the clock never starts |

The third was added after the 2026-09-08 outage and covers the state *before*
this one: sends taken but not completing. Once the pool empties, `in_flight`
sits at its floor and there is nothing left to be waiting on.

### The recovery disarmed the detector

That is not a guess. On 2026-09-12 the callback rung **did** fire, at the exact
onset:

```
14:44:39   hub SELF-REINIT of ESP-NOW — TX wedge on the SEND CALLBACK for 6s
14:44:44   WEDGE mount=1 ... HUB-SIDE OR MOUNT-SIDE
14:45:00   ...and every eight seconds after that, for 2 h 40 m
```

One reinit, and then silence. The ladder never reached its 14-second WiFi bounce
or its 25-second restart, and the hub's uptime ran unbroken from 2.26 h to
3.37 h through the whole outage.

The reason is the shape of the clock. `cb_stall` only runs while something is
outstanding — and the reinit discards whatever was in flight, so `in_flight`
drops to zero. After that the pool is empty, every send is refused, nothing ever
becomes outstanding, and nothing is ever owed a callback. **The rung's own
recovery action removed the condition the rung watches for.** It could not fire
again no matter how long the fault ran.

So the sequence is:

```
callbacks stall
  -> reinit at 6 s
     -> does not cure it, but resets in_flight to 0
        -> cb_stall can never start again
           -> pool stays empty, every send refused
              -> ladder permanently blind, by construction
                 -> hours
```

This is the property the new rung was designed against. Its clock is cleared by
**an accepted send and nothing else** — not by the reinit, not by the WiFi
bounce, not by a restart attempt. A recovery that does not work leaves the clock
running, so the ladder escalates instead of falling silent. A recovery that works
clears it on the first frame the driver takes.

One expectation follows from the above: the 6-second reinit rung has already
been tried against this fault once and did not cure it, so escalation to the
14-second bounce and the 25-second restart should be expected rather than treated
as a surprise.

## What was measured, once it could be

Rejections now reach the clients as an event carrying the error **name**, because
the name is the diagnosis — `NO_MEM` is an exhausted pool, `NOT_FOUND` is a peer
entry that has vanished and a refresh fixes it, `IF` is the wrong interface.
Within hours:

```
21:07:19  ESP-NOW REFUSED a send to cam2 — NO_MEM (+91 since the last report)
21:07:22  ESP-NOW REFUSED a send to cam3 — NO_MEM (+102 since the last report)
21:07:46  ESP-NOW REFUSED a send to cam1 — NO_MEM (+116 since the last report)
```

About 100 refusals per mount per 30 seconds, continuously, on all three directly
radioed mounts. 444 events in the first episode.

## Only a reboot clears it

The mounts do not lack a recovery path — they have one and it runs. Through the
2 h 40 m episode, cam1 fired roughly **230 ESP-NOW stack reinits**, one every 45
seconds, and logged thousands of failed sends. cam2 and cam3 did the same. None
of it made any difference.

One hub reboot cleared it in seconds, every time. That matches the 2026-08-11
finding from the other end: 99 consecutive `esp_wifi_stop()/start()` cycles on a
mount left its failure rate unchanged, and a single chip reboot cleared it for
fourteen hours at identical signal.

## The mitigation

A fourth rung, armed on the refusal itself. First `NO_MEM` stamps a clock, **any
accepted send clears it**, and three seconds without the driver taking a single
frame drops into the existing ladder — reinit at 6 s, WiFi bounce at 14 s,
restart at 25 s.

Two properties make it safe to reboot a production hub on, and both are pinned by
a test:

- **`NO_MEM` only.** `NOT_FOUND` is one unbound peer and `IF` is a configuration
  mistake. Neither is cured by a reboot, and a hub that reboots over them is
  worse than the fault.
- **Any accepted send clears the clock.** The pool is one global resource, so a
  single frame taken proves it is not exhausted. This is what stops a queue that
  briefly fills — 30–90 ms to drain, measured — from ever reaching three seconds.

A consequence worth stating: **the rung cannot be tested on demand.** Forcing
`NO_MEM` with an uncapped burst produces a queue that drains in under a tenth of
a second, so the clock clears long before the threshold. The same property that
makes the threshold safe makes it unprovable by anything but the real fault.

## Reading your own logs for this

The discriminator is the route. A mount reached through a satellite answers over
Ethernet and its reply never touches the hub's radio — so:

- **several direct mounts silent at once + a relayed one answering** = the hub's
  radio specifically, and no mount needs touching
- **one direct mount silent** = ambiguous, and equally that mount's own radio
- **a relayed mount silent** = look at its relay, not at the mount

That third case cost real trips before it was written down: the verdict blamed
the mount and recommended a power cycle — a truss climb, a re-home and a full
recalibration — for a mount whose relay was refusing every frame it was offered
and which recovered untouched when that relay restarted.

## It is a known, open ESP-IDF bug

espressif/esp-idf **#18682** (IDFGH-17756), open and assigned, reports the same
fault on the same chip family:

> ESP-NOW send leaks WiFi TX buffer pool ... `ESP_ERR_ESPNOW_NO_MEM`, only
> recovered by full WiFi.mode teardown

Their conditions differ from ours — broadcast frames at 20 Hz in station mode,
saturating deterministically at ~78,000 frames, with 32 dynamic plus 32 static TX
buffers — where ours is unicast to five peers from a SoftAP with 8 static buffers
and no dynamic pool. The failure is identical in every other respect, including
the two things hardest to explain:

- **`esp_now_deinit()` + `esp_now_init()` does not recover it.** Their conclusion
  from that is the important one: the buffers are held in the **Wi-Fi TX pool**,
  not in ESP-NOW's own state, so tearing down ESP-NOW alone cannot release them.
- **Callbacks that never fire.** They measure roughly one send in 2,400 whose
  send-complete callback never arrives, each one holding its buffer permanently.
  That is a rate, which is why time-to-failure varies with traffic rather than
  being a fixed interval.

Their pool is eight times larger than ours and still saturates. **More buffers
delay it; they do not prevent it.**

### What that rules out

**Upgrading ESP-IDF will not fix this.** The v6.1 release notes contain no
changes to ESP-NOW, the Wi-Fi TX path, or TX buffer handling. The only ESP-NOW
change in v6.0 is the removal of `esp_wifi_config_espnow_rate()` in favour of
`esp_now_set_peer_rate_config()`, which this firmware already uses. #18682 is
open against v5.5.4 with no fix and no workaround identified.

**Changing the TX buffer configuration will not fix it either**, for the reason
above — the reporter's larger pool fails the same way.

### What it confirms about the recovery

The sequence #18682 identifies as the only reliable recovery is the one this
firmware already performs at the 14-second rung:

```c
esp_now_deinit();
WiFi.softAPdisconnect(true);
WiFi.mode(WIFI_OFF);
delay(200);
WiFi.mode(WIFI_AP);  /* + softAPConfig, softAP, ps NONE */
hub_espnow_rebuild();            /* init, callbacks, peers */
```

So the cure was already written and had simply never been reached, because the
detector disarmed itself at the 6-second rung. With a clock that an unsuccessful
recovery cannot clear, the ladder now escalates into it.

**Expect recovery at the 14-second rung, not the 25-second restart.** This
supersedes an earlier note in this document predicting otherwise: that was
written from the observation that the 6-second reinit failed, before it was known
that the 14-second bounce is the specific action that works.

## Still unknown

**Why a callback goes missing.** #18682 measures the rate and not the cause, and
neither have we. Roughly 140 hours of two-board bench work never reproduced it —
see `2026-09-13-bench-verdict.md`.

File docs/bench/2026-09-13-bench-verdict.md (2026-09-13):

# The ESP-NOW bench: what 140 hours established, and why it stopped

Closing report on `firmware/espnow_bench`, a two-board rig built to answer one
question. It never answered it. It was still worth building, and this records
both halves so the next person does not rebuild it expecting more.

## The question it was built for

A node's ESP-NOW transmit path stops. `esp_now_send()` begins returning
`ESP_ERR_ESPNOW_NO_MEM`, the send-complete callback stops firing, and nothing
short of a chip reboot clears it. espressif/esp-idf#18682 describes the
mechanism — a buffer taken from a small pool, returned by a callback that never
comes — so the open question was never "why does the pool run out". It was:

> **Why does the callback stop?**

On the rig the fault takes hours, the mounts are in enclosures on a truss with
no reachable serial port, and the restart that ends it resets every counter that
would explain it. Two boards on a desk with USB on both, and every experiment a
typed line rather than a reflash, was the answer to that.

## The instrument that mattered

```
in_flight = issued - (cb_ok + cb_fail)
```

The leaked-buffer count, and the one number the rig had never had. A refusal
count cannot warn — it only moves once the pool is already empty, and by then the
radio cannot report it. `in_flight` starts climbing at the first lost buffer.
Tracked as the **floor** it has not returned below over a 5-second window, because
the instantaneous value bounces with every send.

## What it established

**The leak is real, and it has a precondition.** Same rate, same everything: no
synthetic load ran 13.3 h and 10.5 M sends with the floor at 0. With `load 40 100`
— 40 ms of blocked loop in every 100 — the floor stepped 0→1→2→3 at 5.97 h,
6.28 h and 15.17 h, each step costing **exactly 208 bytes of heap, never
returned**. It leaked at a *lower* send rate than the run that did not.

**It needs three or more sends in flight, not merely overlapping ones.** The
capped run overlapped *more* often per send than the leaking one — 101 per 1000
against 43 — and stayed clean. The cap bounds depth, not concurrency.

**`cap 2` prevents it.** 53.32 h, 26,868,324 sends, floor 0, heap drift of
exactly 0 bytes, one continuous session. Against the uncapped rate of one leak
per 2.53 M sends, 10.6 were expected and none occurred: **p ≈ 2.4 × 10⁻⁵**.

**The send queue holds exactly 32, and it drains.** `esp_now_send()` accepts 32
back to back before refusing — invariant to payload size and to PHY rate — and
all 32 callbacks return within 30–90 ms. It is a fixed-count descriptor queue
above `CONFIG_ESP_WIFI_STATIC_TX_BUFFER_NUM`, which is 8. **So an in-flight floor
of 32 is saturation, not loss**: `in_flight` physically cannot exceed it, and the
number says nothing about how long a stall ran.

## What it falsified

Five explanations, every one of them ours, each killed in minutes rather than
over nights of rig observation. This is what the bench was actually for.

| claim | measurement that killed it |
|---|---|
| A floor of 32 is sends piling up during a stall | It is a ceiling, reached in under a millisecond with nothing stalled, and it drains completely |
| A cap cannot help the rig — its average send rate is too low | Averages hide bursts; the blocked loop manufactures one, and `cap 2` prevented the leak |
| `cb_fail` means the frame was lost | 18 failures, 0 gaps: all eighteen delivered, the acknowledgements were lost |
| ...so `cb_fail` means the frame arrived | 1 failure, 1 gap, same sequence number: genuinely lost. It means neither reliably |
| AP mode is the last structural difference from the hub | 20.7 h with a station associated, 8.94 M sends, floor 0 |

The through-line: **the gap counter is ground truth precisely because it does not
depend on `cb_fail`**, and a decision table built on a counter that is ambiguous
in both directions has to be read against something independent.
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

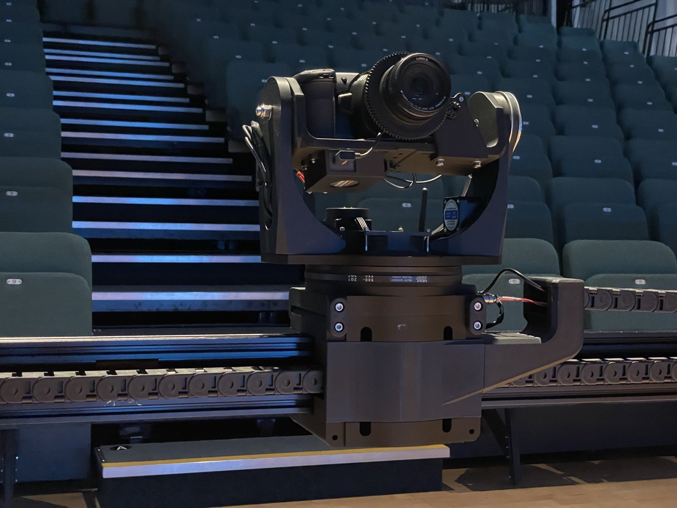
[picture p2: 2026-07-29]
docs/assets/img/mount-rail.jpg

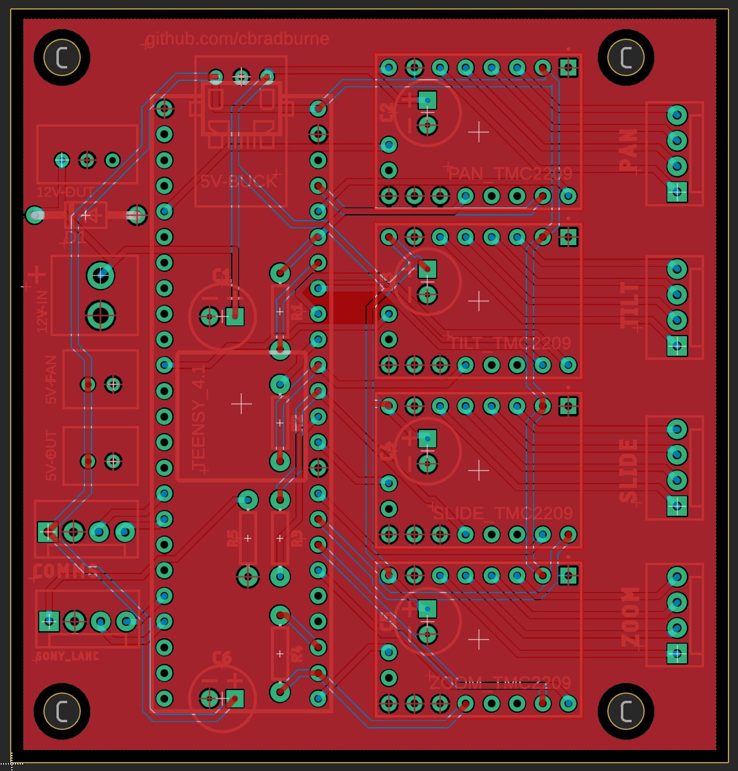
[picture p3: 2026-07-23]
docs/assets/img/pcb.jpg

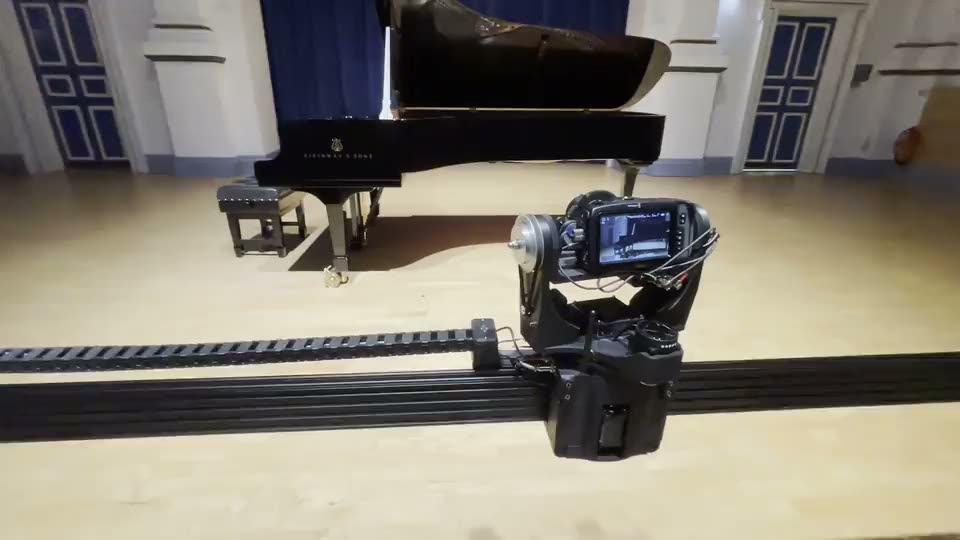
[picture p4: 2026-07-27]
docs/assets/img/slider-rail.jpg

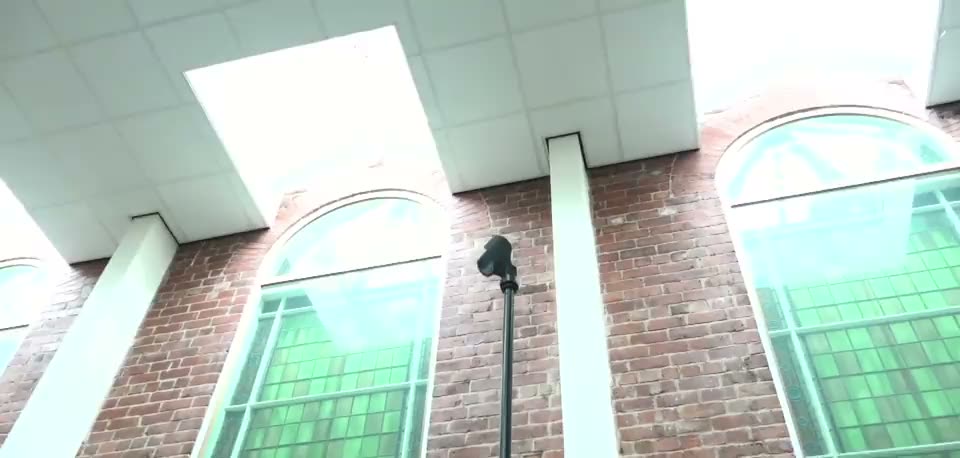
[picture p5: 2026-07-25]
docs/assets/img/lookat-move.jpg

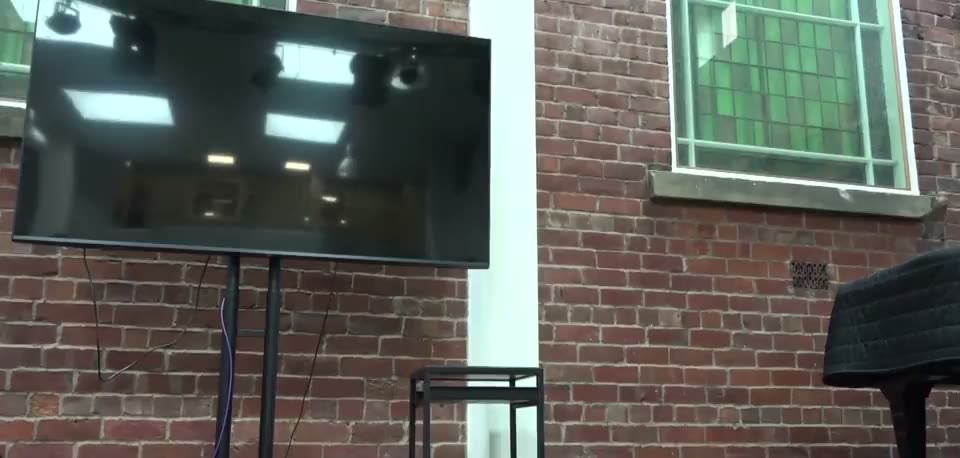
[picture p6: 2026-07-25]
docs/assets/img/lookat-reaim.jpg

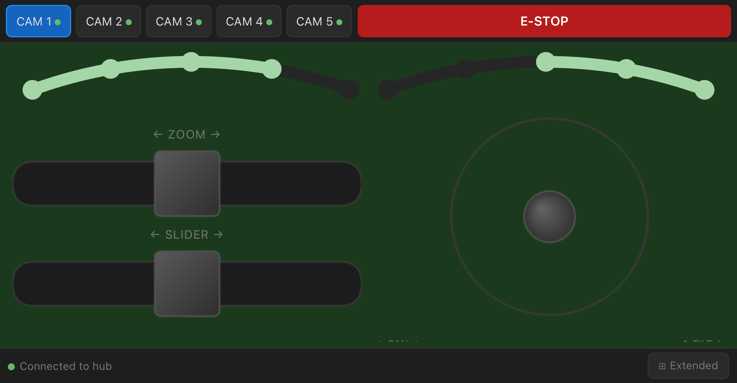
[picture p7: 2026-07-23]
docs/assets/img/phone-landscape.png

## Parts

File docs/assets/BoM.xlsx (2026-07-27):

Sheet: Parts
Item | Qty | Buy
Circuit
Teensy 4.1 | 1 | Amazon (https://www.amazon.co.uk/dp/B0BCTSKYQZ?ref=ppx_yo2ov_dt_b_fed_asin_title)
TMC2209 | 4 | Amazon (https://www.amazon.co.uk/dp/B07WC71M4R?ref=ppx_yo2ov_dt_b_fed_asin_title&th=1)
5V regulator | 1 | Amazon (https://www.amazon.co.uk/dp/B09Z2BM94R?ref_=ppx_hzsearch_conn_dt_b_fed_asin_title_1)
1n4007 | 2 | Amazon (https://www.amazon.co.uk/sourcing-map-Rectifier-Electronic-Industrial/dp/B0FZFSXY79/)
100nf 35v | 6 | Amazon (https://www.amazon.co.uk/dp/B08MZ1BSN6?ref_=ppx_hzsearch_conn_dt_b_fed_asin_title_3)
1K ¼W | 4 | Amazon (https://www.amazon.co.uk/dp/B0CL6XM7RD/)
100K ¼W | 1 | Amazon (https://www.amazon.co.uk/dp/B0CL6TJZPC/)
Screw PCB terminals 5.08mm 2pin | 1 | Amazon (https://www.amazon.co.uk/sourcing-map-Connectors-Connector-Electronic/dp/B0G8YZSX2B/)
JST 4pin Plug + Lead + Socket | 6 | Amazon (https://www.amazon.co.uk/dp/B09LCRCTQG?ref_=ppx_hzsearch_conn_dt_b_fed_asin_title_5)
JST 5pin Plug + Lead + Socket | 1 | Amazon (https://www.amazon.co.uk/dp/B0CBWZBB63?ref_=ppx_hzsearch_conn_dt_b_fed_asin_title_3&th=1)
JST 2pin Plug + Lead + Socket | 2 | Amazon (https://www.amazon.co.uk/dp/B0CBWZLB5C?ref_=ppx_hzsearch_conn_dt_b_fed_asin_title_1&th=1)
Header Sockets | Pack | Amazon (https://www.amazon.co.uk/dp/B00R1JDS1Q?ref=ppx_yo2ov_dt_b_fed_asin_title)
Header Pins | Pack | Amazon (https://www.amazon.co.uk/dp/B0GZZXN23M/)
Mount
6824ZZ 120x150x16mm Bearing | 1 | Simply Bearings (https://simplybearings.co.uk/shop/p170416/6824ZZ-Budget-Metal-Shielded-Thin-Section-Deep-Groove-Ball-Bearing-120x150x16mm/product_info.html)
F688ZZ Flanged Bearing 8 x 16 x 5mm | 4 | Amazon (https://www.amazon.co.uk/dp/B0CRLSHL1N?ref_=ppx_hzsearch_conn_dt_b_fed_asin_title_1&th=1)
GT2 Pulley - 120 tooth, 8mm bore | 1 | Amazon (https://www.amazon.co.uk/dp/B09DS9PJ55?ref_=ppx_hzsearch_conn_dt_b_fed_asin_title_6&th=1)
GT2 Pulley - 36 tooth, 5mm bore | 1 | Amazon (https://www.amazon.co.uk/dp/B07X8776QQ?ref_=ppx_hzsearch_conn_dt_b_fed_asin_title_4)
GT2 Pulley - 16 tooth, 5mm bore | 1 | Amazon (https://www.amazon.co.uk/dp/B07SX1N19C/?th=1)
GT2 Belt - 580mm loop, 6mm wide | 1 | Amazon (https://www.amazon.co.uk/dp/B07RCZPRG9?ref_=ppx_hzsearch_conn_dt_b_fed_asin_title_5)
GT2 Belt - 350mm loop, 6mm wide | 1 | Amazon (https://www.amazon.co.uk/sourcing-map-Timing-Printing-Closed/dp/B0GVKNPKQV/?th=1)
Nema17 0.9 deg 36Ncm | 2 | Amazon (https://www.amazon.co.uk/dp/B00W98OYE4?ref_=ppx_hzsearch_conn_dt_b_fed_asin_title_2)
Nema14 Round Pancake Stepper Motor 0.9 deg | 1 | Amazon (https://www.amazon.co.uk/dp/B0B9RVCDTJ?ref_=ppx_hzsearch_conn_dt_b_fed_asin_title_3)
GX12 2 Pin Aviation Connector & Panel Socket | 1 | Amazon (https://www.amazon.co.uk/dp/B0DX5PVGJ9?ref_=ppx_hzsearch_conn_dt_b_fed_asin_title_1&th=1)
Waveshare ESP32-S3 1.75inch AMOLED Round Touch Display | 1 | Amazon (https://www.amazon.co.uk/dp/B0F7XTJ1ZL?ref=ppx_yo2ov_dt_b_fed_asin_title)
Sticky Pads Heavy Duty 40x40mm | 1 | Amazon (https://www.amazon.co.uk/dp/B0GQRJJPFN?ref=ppx_yo2ov_dt_b_fed_asin_title&th=1)
2.4GHz Antenna | 1 | Amazon (https://www.amazon.co.uk/dp/B0DTHJ1FS2?ref=ppx_yo2ov_dt_b_fed_asin_title)
U.FL Mini PCI to SMA Female 20cm Lead | 1 | Amazon (https://www.amazon.co.uk/dp/B0B9RXM7TB?ref=ppx_yo2ov_dt_b_fed_asin_title&th=1)
1/4" UNC Thumb Screw | 1 | Amazon (https://www.amazon.co.uk/gp/product/B0748CQ4RK/)
12V 8A Power Supply | 1 | Amazon (https://www.amazon.co.uk/gp/product/B0B5KL92RH/)
Mount - HDMI
HDMI Keystone coupler | 1 | Amazon (https://www.amazon.co.uk/dp/B07Z8YS2Z7?ref_=ppx_hzsearch_conn_dt_b_fed_asin_title_1&th=1)
HDMI Cable - 1m | 1 | Amazon (https://www.amazon.co.uk/dp/B09L4XKVQ5/)
Mount - SDI
SDI Panel mount coupler | 1 | Amazon (https://www.amazon.co.uk/dp/B0FSCXSPCB?ref_=ppx_hzsearch_conn_dt_b_fed_asin_title_1&th=1)
HD-SDI Cable - 1m | 1 | Amazon (https://www.amazon.co.uk/dp/B07Y9GPG8X/)
Mount - BMD Converter
Blackmagic Design Bi-Directional SDI/HDMI 3G | 1 | Thomann (https://www.thomann.co.uk/blackmagic_design_mc_bidirect._sdi_hdmi_3g.htm)
SDI Panel mount coupler | 2 | Amazon (https://www.amazon.co.uk/dp/B0FSCXSPCB?ref_=ppx_hzsearch_conn_dt_b_fed_asin_title_1&th=1)
HD-SDI Cable - 1m, Right angle | 2 | Amazon (https://www.amazon.co.uk/gp/product/B0CZ3TBTJM/)
USB-C Cable - 1 Metre (cut and soldered to JST 2pin) | 1 | Amazon (https://www.amazon.co.uk/dp/B07PLSDPYN/)
Slider
Aluminium Extrusion - 8040 C | 1000 - 3000mm | Ooznest (https://ooznest.co.uk/product/40x80mm-c-beam-t-v-slot-aluminium-extrusion-profile-silver-cut-to-size/?mtke=11)
GT2 Pulley - 36 tooth | 1 | Amazon (https://www.amazon.co.uk/dp/B07X8776QQ?ref_=ppx_hzsearch_conn_dt_b_fed_asin_title_4)
GT2 Belt - 5m | 1 | Amazon (https://www.amazon.co.uk/dp/B08SJ5X2HZ?ref_=ppx_hzsearch_conn_dt_b_fed_asin_title_9&th=1)
Idler - 6mm width, 3mm bore, 13mm diameter | 2 | Amazon (https://www.amazon.co.uk/dp/B0CD25SZNR?ref_=ppx_hzsearch_conn_dt_b_fed_asin_title_1&th=1)
Nema17 1.8 deg 65Ncm | 1 | Amazon (https://www.amazon.co.uk/dp/B00PNEQUZ2?ref_=ppx_hzsearch_conn_dt_b_fed_asin_title_1)
V Slot Pulley Wheels 625zz | 16 | Amazon (https://www.amazon.co.uk/sourcing-map-Printer-Rollers-High-Speed/dp/B0DNCP6TRB/)
XT60 Plug Connector Female and Male | 1 | Amazon (https://www.amazon.co.uk/dp/B085HF31K7?ref_=ppx_hzsearch_conn_dt_b_fed_asin_title_1)
GX12 2 Pin Aviation Connector & Panel Socket | 1 | Amazon (https://www.amazon.co.uk/dp/B0DX5PVGJ9?ref_=ppx_hzsearch_conn_dt_b_fed_asin_title_1&th=1)
GX12 4 Pin Aviation Connector & Panel Socket | 1 | Amazon (https://www.amazon.co.uk/dp/B0DX6CD9LN?ref_=ppx_hzsearch_conn_dt_b_fed_asin_title_1&th=1)
Drag Chain R38 18X25mm 1.5m | 1-3 | Amazon (https://www.amazon.co.uk/dp/B07MMCWWHC/)
Slider - HDMI
HDMI Keystone coupler | 1 | Amazon (https://www.amazon.co.uk/dp/B07Z8YS2Z7?ref_=ppx_hzsearch_conn_dt_b_fed_asin_title_1&th=1)
HDMI Cable, 2m - 4m | 1 | Amazon (https://www.amazon.co.uk/dp/B09ZRTQXXT/?th=1)
Slider - SDI
SDI Panel mount coupler | 1 | Amazon (https://www.amazon.co.uk/dp/B0FSCXSPCB?ref_=ppx_hzsearch_conn_dt_b_fed_asin_title_1&th=1)
HD-SDI Cable, 1m - 4m | 1 | Amazon (https://www.amazon.co.uk/dp/B07VRBYT1N/)
Slider - BMD Converter
SDI Panel mount coupler | 2 | Amazon (https://www.amazon.co.uk/dp/B0FSCXSPCB?ref_=ppx_hzsearch_conn_dt_b_fed_asin_title_1&th=1)
HD-SDI Cable, 2m - 4m | 2 | Amazon (https://www.amazon.co.uk/dp/B07VRBYT1N/)
Hub
Seeed Studio XIAO ESP32S3 | 1 | Amazon (https://www.amazon.co.uk/dp/B0BYSB66S5?ref=ppx_yo2ov_dt_b_fed_asin_title&th=1)
Hub Display
Waveshare ESP32-S3 7inch Capacitive Touch LCD | 1 | Amazon (https://www.amazon.co.uk/dp/B0D2NMCY7K/)
2.4GHz Antenna | 1 | Amazon (https://www.amazon.co.uk/dp/B0DTHJ1FS2?ref=ppx_yo2ov_dt_b_fed_asin_title)
U.FL Mini PCI to SMA Female 20cm Lead | 1 | Amazon (https://www.amazon.co.uk/dp/B0B9RXM7TB?ref=ppx_yo2ov_dt_b_fed_asin_title&th=1)
USB-C Screw Hole Panel Mount | 1 | Amazon (https://www.amazon.co.uk/dp/B075R7QBQD/?th=1)
Misc
2 Core Wire - 30m, 20awg | 1 | Amazon (https://www.amazon.co.uk/dp/B0792Y2X4K/)
4 Core Wire - 10m, 24awg | 1 | Amazon (https://www.amazon.co.uk/dp/B0CP6XLLX8/)
Optional
UGREEN Video Capture Card HDMI to USB C 1080P 60FPS Capture (CV Tracking) | 1 | Amazon (https://www.amazon.co.uk/dp/B0CFQ2BMPZ?ref=ppx_yo2ov_dt_b_fed_asin_title)
Soldering Iron Tips for Threaded Inserts | 1 | Amazon (https://www.amazon.co.uk/dp/B0CS662NVK)
10ft - 1/2 inch Braided Cable Sleeve | 1 | Amazon (https://www.amazon.co.uk/dp/B0D6QZSZ4P)

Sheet: Nuts&Bolts
Base + Topper + Ports |  |  | Inner |  | Upper |  |  | Camera Focus + Converter |  |  | Side-Support |  | Side-Motor |  |  | Camera |  |  | Tripod Mount |  | Comms Mount |  | Hub Display
M2.5 Insert | 4 | Sockets | M3 Insert | 12 | M3 Insert | 4 |  | M3 Insert | 4 |  | M3 x 30 | 2 | M3 x 16 | 4 | motor | M8 x 25 | 1 |  | M5 Nyloc Nut | 4 | M2 Counter Sunk x 6 | 3 | M3 Insert | 4
M3 Insert | 16 |  |  |  |  |  |  | M5 Nyloc Nut | 2 |  | M3 x 45 | 1 | M3 x 30 | 2 |  | M8 x 45 | 1 | Pulley | 1/4 UNC Insert | 1
M5 P Nyloc Nut | 4 |  | M3 x 8 | 4 | M3 x 10 | 4 | motor |  |  |  |  |  | M3 x 45 | 1 |  |  |  |  |  |  |  |  | M3 x 8 | 4
 |  |  |  |  | M3 x 30 | 6 |  | M3 Counter Sunk x 10 | 2 |  | M3 Washer | 3 |  |  |  | M8 Domed Nut | 2 |  | M5 x 20 | 4
M2.5 Counter Sunk x 8 | 4 | Sockets |  |  |  |  |  | M3 x 16 | 4 |  |  |  | M3 Washer | 7 |  | 1/4” Camera Thumb Screw | 1 |  | M5 x 30 | 4 |  |  | M3 Washer | 4
 |  |  |  |  | M3 Washer | 10 |  | M5 x 25 | 2 |  | Bearings | 2
M3 Counter Sunk x 10 | 4 | Optional |  |  |  |  |  | M3 Washer | 4 |  |  |  | Bearings | 2
M3 x 12 | 8 | 4 Optional
M3 x 20 | 2
M3 x 45 | 6
M3 Washer | 8 | 4 Optional
Rail End-Comms |  |  | Rail End |  | Rail Bottom |  |  | Rail Top |  |  | Rail Side Drag |  | Rail Side Motor |  |  | Rail Drag Arm |  |  | Rail Drag Clip |  | Slider Tripod Mount
M3 Nyloc Nut | 7 |  | 1/4 UNC Insert | 1 | M5 Nyloc Nut | 6 |  | M5 Nyloc Nut | 6 |  | M5 Nyloc Nut | 6 | M5 Nyloc Nut | 4 |  | M3 Nyloc Nut | 2 |  | M3 Nyloc Nut | 4 | 1/4 UNC Insert | 2
M3 Insert | 4
1/4 UNC Insert | 1 |  | M5 x 25 | 4 | M5 x 35 | 2 | (drag-side) | M5 x 35 | 2 | (drag-wheels) | M5 x 20 | 2 | M3 x 10 | 4 |  | M5 x 20 | 2 |  | M3 Counter Sunk x 10 | 4 | 1/4 UNC x 1½" | 2
 |  |  | M5 x 35 | 2 | M5 x 45 | 2 | (motor-wheels) | M5 x 45 | 2 | (motor-wheels) |  |  | M3 Washer | 4
M2.5 Counter Sunk x 8 | 2 |  |  |  | M5 x 55 | 2 | (bottom-wheels) | M5 x 55 | 2 | (top-wheels) |  |  |  |  |  |  |  |  | M3 x 20 | 2
 |  |  | M5 Washer | 4 |  |  |  |  |  |  |  |  |  |  |  |  |  |  | M3 Washer | 2
M3 x 16 | 2 |  |  |  | M3 x 25 | 2 | (optional cover)
M3 x 25 | 1 |  |  |  | M3 Washer | 2 | (optional cover)
M3 Counter Sunk x 10 | 4
M5 x 25 | 4
M3 Washer | 2
M5 Washer | 4

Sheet: Nuts&Bolts-List
Fastener | Base + Topper + Ports | Inner | Upper | Camera Focus + Converter | Side-Support | Side-Motor | Camera | Tripod Mount | Comms Mount | Hub Display | Rail End-Comms | Rail End | Rail Bottom | Rail Top | Rail Side Drag | Rail Side Motor | Rail Drag Arm | Rail Drag Clip | Slider Tripod Mount | Total | Link
M3 x 8 |  | 4 |  |  |  |  |  |  |  | 4 |  |  |  |  |  |  |  |  |  | 8 | Amazon (https://www.amazon.co.uk/gp/product/B0DYP14R1H/)
M3 x 10 |  |  | 4 |  |  |  |  |  |  |  |  |  |  |  |  | 4 |  |  |  | 8 | Amazon (https://www.amazon.co.uk/gp/product/B0DZ1M6HSH/)
M3 x 12 | 8 |  |  |  |  |  |  |  |  |  |  |  |  |  |  |  |  |  |  | 8 | Amazon (https://www.amazon.co.uk/gp/product/B0DZ1PLWD4/)
M3 x 16 |  |  |  | 4 |  | 4 |  |  |  |  | 2 |  |  |  |  |  |  |  |  | 10 | Amazon (https://www.amazon.co.uk/gp/product/B0DZ1NR6NB/)
M3 x 20 | 2 |  |  |  |  |  |  |  |  |  |  |  |  |  |  |  |  | 2 |  | 4 | Amazon (https://www.amazon.co.uk/gp/product/B0DZ1PVK8Q/)
M3 x 25 |  |  |  |  |  |  |  |  |  |  | 1 |  | 2 |  |  |  |  |  |  | 3 | Amazon (https://www.amazon.co.uk/gp/product/B0DZ1P596F/)
M3 x 30 |  |  | 6 |  | 2 | 2 |  |  |  |  |  |  |  |  |  |  |  |  |  | 10 | Amazon (https://www.amazon.co.uk/gp/product/B0DZ1MXJBG/)
M3 x 45 | 6 |  |  |  | 1 | 1 |  |  |  |  |  |  |  |  |  |  |  |  |  | 8 | Amazon (https://www.amazon.co.uk/gp/product/B0DZ1MY37R/)
M2 Counter Sunk x 6 |  |  |  |  |  |  |  |  | 3 |  |  |  |  |  |  |  |  |  |  | 3 | Amazon (https://www.amazon.co.uk/dp/B0BR4WQP4R)
M2.5 Counter Sunk x 8 | 4 |  |  |  |  |  |  |  |  |  | 2 |  |  |  |  |  |  |  |  | 4 | Amazon - As above (https://www.amazon.co.uk/dp/B0BR4WQP4R)
M3 Counter Sunk x 10 | 4 |  |  | 2 |  |  |  |  |  |  | 4 |  |  |  |  |  |  | 4 |  | 14 | Amazon - As above (https://www.amazon.co.uk/dp/B0BR4WQP4R)
M5 x 20 |  |  |  |  |  |  |  | 4 |  |  |  |  |  |  | 2 |  | 2 |  |  | 8 | Amazon (https://www.amazon.co.uk/gp/product/B0D6B63D9M/)
M5 x 25 |  |  |  | 2 |  |  |  |  |  |  | 4 | 4 |  |  |  |  |  |  |  | 10 | Amazon (https://www.amazon.co.uk/gp/product/B0D6B553V8/)
M5 x 30 |  |  |  |  |  |  |  | 4 |  |  |  |  |  |  |  |  |  |  |  | 4 | Amazon (https://www.amazon.co.uk/gp/product/B0D6B4VQQY/)
M5 x 35 |  |  |  |  |  |  |  |  |  |  |  | 2 | 2 | 2 |  |  |  |  |  | 6 | Amazon (https://www.amazon.co.uk/gp/product/B0D6B631ZL/)
M5 x 45 |  |  |  |  |  |  |  |  |  |  |  |  | 2 | 2 |  |  |  |  |  | 4 | Amazon (https://www.amazon.co.uk/gp/product/B0D6B58X5N/)
M5 x 55 |  |  |  |  |  |  |  |  |  |  |  |  | 2 | 2 |  |  |  |  |  | 4 | Amazon (https://www.amazon.co.uk/gp/product/B0D6B4PHN3/)
1/4 UNC x 1½" |  |  |  |  |  |  |  |  |  |  |  |  |  |  |  |  |  |  | 2 | 2 | Amazon (https://www.amazon.co.uk/dp/B07KM41WMS)
M8 x 25 |  |  |  |  |  |  | 1 |  |  |  |  |  |  |  |  |  |  |  |  | 1 | Amazon (https://www.amazon.co.uk/dp/B09XJJTD1T)
M8 x 45 |  |  |  |  |  |  | 1 |  |  |  |  |  |  |  |  |  |  |  |  | 1 | Amazon (https://www.amazon.co.uk/dp/B09XJGZVPM)
M2.5 Insert | 4 |  |  |  |  |  |  |  |  |  |  |  |  |  |  |  |  |  |  | 4 | Amazon (https://www.amazon.co.uk/dp/B0CS662NVK)
M3 Nyloc Nut |  |  |  |  |  |  |  |  |  |  | 7 |  |  |  |  |  | 2 | 4 |  | 13 | Amazon (https://www.amazon.co.uk/dp/B0FC5N6KCW/)
M3 Insert | 16 | 12 | 4 | 4 |  |  |  |  |  | 4 | 4 |  |  |  |  |  |  |  |  | 44 | Amazon (https://www.amazon.co.uk/dp/B0BS3LH9K9)
M5 Nyloc Nut |  |  |  | 2 |  |  |  | 4 |  |  |  |  | 6 | 6 | 6 | 4 |  |  |  | 28 | Amazon (https://www.amazon.co.uk/dp/B09THKYY5R/)
M8 Domed Nut |  |  |  |  |  |  | 2 |  |  |  |  |  |  |  |  |  |  |  |  | 2 | Amazon (https://www.amazon.co.uk/dp/B0FBWVXTDG/)
1/4 UNC Insert |  |  |  |  |  |  |  | 1 |  |  | 1 | 1 |  |  |  |  |  |  | 2 | 5 | Amazon (https://www.amazon.co.uk/dp/B0B1F7NMJ5/)
M3 Washer | 8 |  | 10 |  | 3 | 7 |  |  |  | 4 | 2 |  | 2 |  |  | 4 |  | 2 |  | 42 | Amazon (https://www.amazon.co.uk/dp/B0F638VSQD/)
M5 Washer |  |  |  |  |  |  |  |  |  |  | 4 |  |  |  |  |  |  |  |  | 4 | Amazon (https://www.amazon.co.uk/dp/B0BFCRFRRF/)

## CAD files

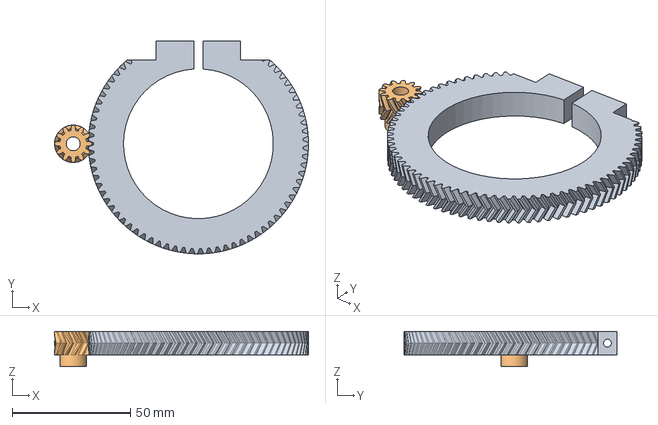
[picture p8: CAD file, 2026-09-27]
Print Files/Optional/Gears - Panasonic 14-150mm F4-5.6.step
107.5 x 90.1 x 15.0 mm
Healical Gear (79R@30.00)
Healical Gear (12R@30.00)

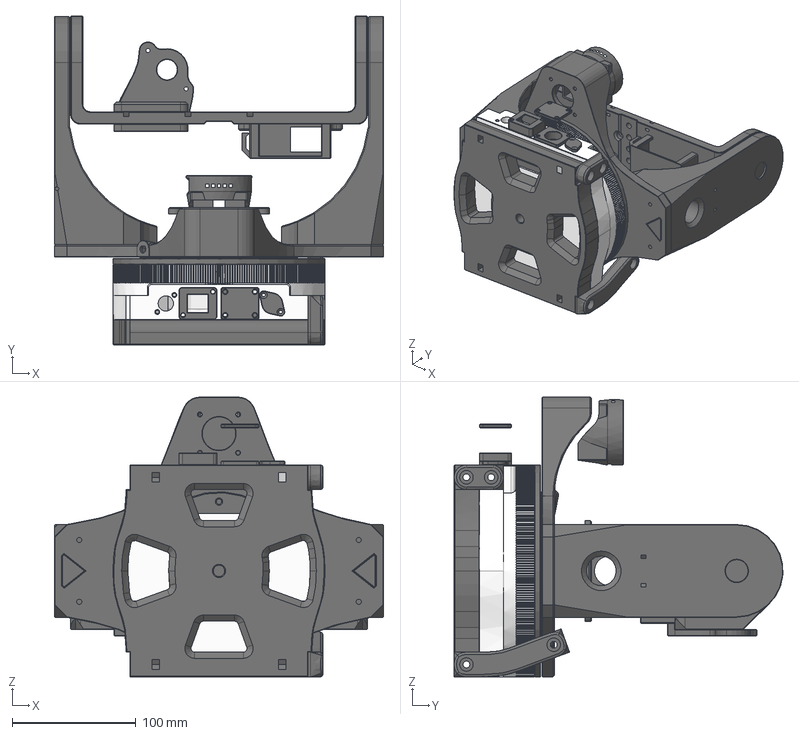
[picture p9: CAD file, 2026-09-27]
Print Files/PT Mount.step
266.0 x 265.9 x 226.2 mm
02 Base Topper
03 Inner Lower TS4 - Inserts
04 Inner Upper
06 Side - Support
07 Side - Motor
11 M5 Nut Filler
17 Bearing Washer
15 Neutrik - BNC
16 Keystone Adapter
01 Base - Full Inserts
18 Plug Filler
10 Tripod Mount w insert
199 SDI Filler
09 Cover
20 - OLED
12 Tilts
05 Upper - Inserts
12 SDI Converter

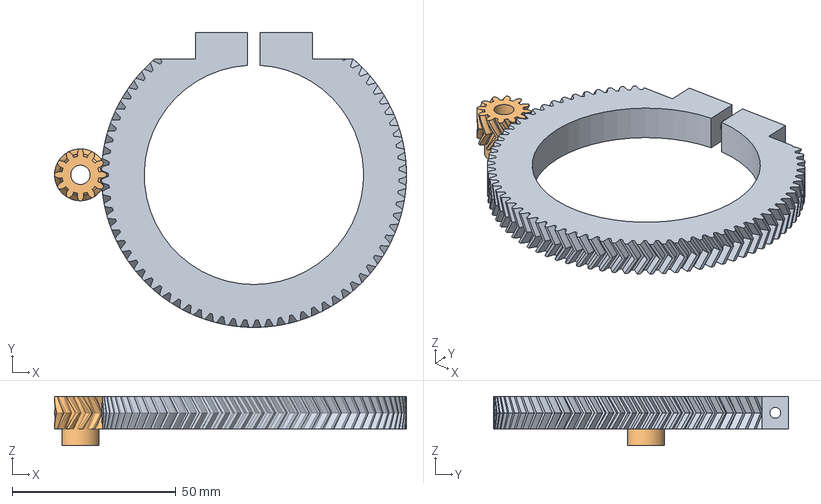
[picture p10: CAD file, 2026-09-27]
Print Files/Optional/Gears - Panasonic 12-35mm.step
107.5 x 90.1 x 15.0 mm
Healical Gear (79R@30.00)
Healical Gear (12R@30.00)

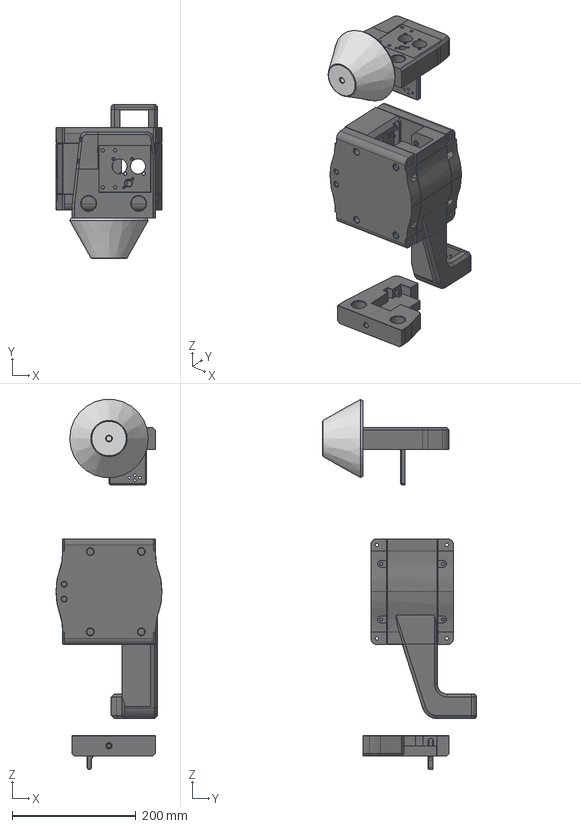
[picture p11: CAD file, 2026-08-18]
Print Files/Slider.step
171.4 x 249.0 x 599.2 mm
14 Drag Support
15 Belt Cam
08 Drag Mount - Inserts
PTS Speaker Pole
12 End A 1/4 inserts
Tripod Cup
01 Bottom FW
04 Side FW
02 Top FW
05 Drag Arm
13 End B 1/4 inserts
09 Motor Cover
03 Side Motor FW

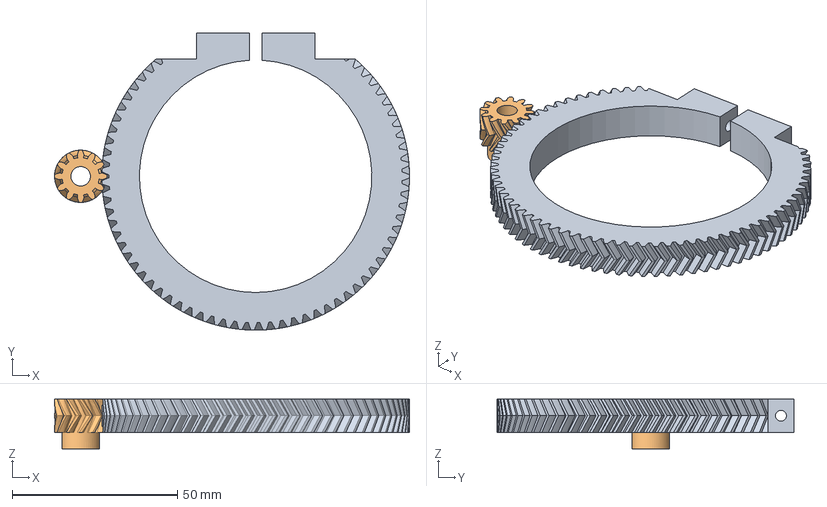
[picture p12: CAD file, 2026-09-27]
Print Files/Optional/Gears - Olympus 12-40mm.step
107.5 x 90.1 x 15.0 mm
Healical Gear (79R@30.00)
Healical Gear (12R@30.00)

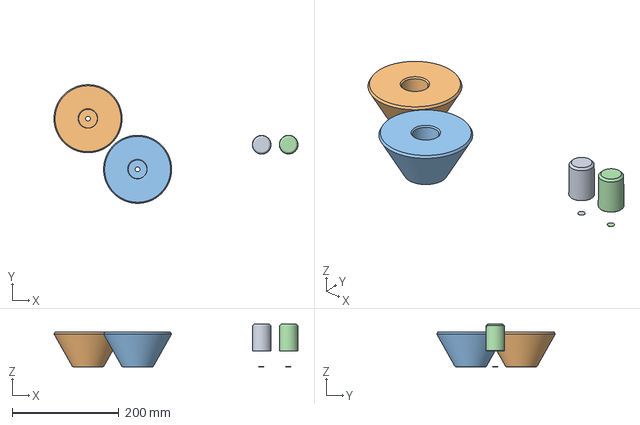
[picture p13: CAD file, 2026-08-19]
Print Files/Optional/Quick Release Pole + Cup.3mf
456.5 x 222.1 x 80.0 mm
PTS Speaker Pole v1 x 2
Tripod Cup v11 x 2

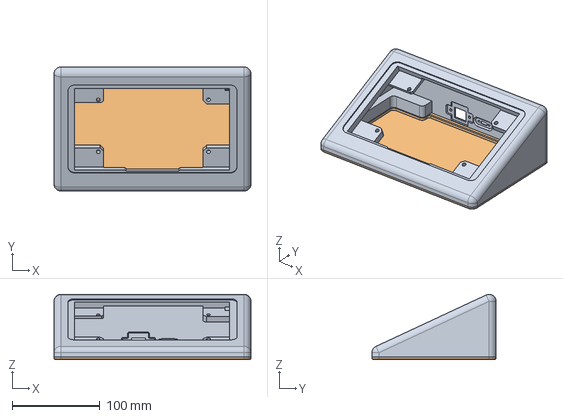
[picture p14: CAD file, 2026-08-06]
Print Files/Optional/Hub Mount.step
225.2 x 142.0 x 74.6 mm

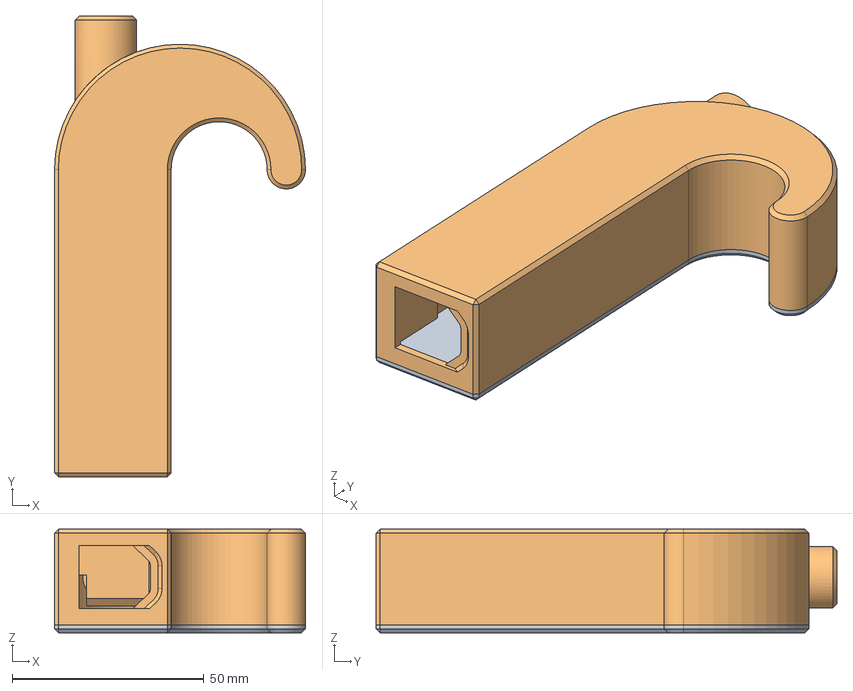
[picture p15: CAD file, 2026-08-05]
Print Files/Optional/Satellite.step
65.4 x 120.0 x 27.0 mm

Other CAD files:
Print Files/Optional/Hub Mount.3mf
Print Files/Optional/Satellite.3mf
Print Files/PT Mount.3mf
Print Files/Slider.3mf

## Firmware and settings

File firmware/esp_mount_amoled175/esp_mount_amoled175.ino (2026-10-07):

/*
 * esp_mount_amoled175 — Mount-side ESP-NOW/Teensy bridge with circular LVGL display
 *
 * Hardware: Waveshare ESP32-S3-Touch-AMOLED-1.75
 *   Display : SH8601Z QSPI  466×466 circular AMOLED
 *             CS=12  CLK=38  D0=4  D1=5  D2=6  D3=7  RST=39
 *   Touch   : CST9217  I2C addr=0x5A  SDA=15  SCL=14  INT=11  RST=40
 *   Teensy  : Serial1  TX=43 RX=44  115200 baud
 *
 * Board settings (Arduino IDE):
 *   Board             : ESP32S3 Dev Module
 *   USB CDC On Boot   : Enabled
 *   Flash Size        : 16MB
 *   PSRAM             : OPI PSRAM
 *
 * Required libraries (Library Manager):
 *   lvgl          by kisvegabor  (v8.3.x)
 *   Arduino_GFX   by moononournation  (needs Arduino_SH8601 driver)
 *
 * lv_conf.h must be in this sketch folder.
 *
 * UI layout (466×466 circle, centre 233,233):
 *   Status ring  — full circle border, 8px wide, colour = connection state
 *   PT arc       — right side, 15 min→2 min  (rotation=12,  bg_angles 0,78, REVERSE)
 *   SL arc       — left side,  45 min→58 min (rotation=270, bg_angles 0,78, NORMAL)
 *   4 detent dots per arc, positioned on R=190 from centre
 *   Centre text  — "CAM" label, large mount number (48pt), state, RSSI
 *   10 slot circles — two rows near the bottom
 *   Touch zones  — left half cycles PT preset, right half cycles SL preset
 */

#define LV_CONF_INCLUDE_SIMPLE
#include <Arduino.h>
#include <lvgl.h>
#include <Arduino_GFX_Library.h>
#include <TouchDrv.hpp>
#include <SensorQMI8658.hpp>
#include <esp_now.h>
#include <WiFi.h>
#include <esp_wifi.h>
#include <esp_task_wdt.h>
#include <Wire.h>
#include "../shared/protocol.h"
#include "../shared/link_run.h"     // a run of unanswered sends, for MOUNT_EVENT_LINK_RUN
#include "../shared/clock_age.h"    // ages against stamps another task writes
#include "../shared/pos_run.h"      // cycling stored positions — the mount's own run
#include "../shared/crash_report.h"
#include "ble_camera.h"   // Blackmagic camera control over BLE
#include "ui_types.h"   // ArcStrip struct — must be included before Arduino auto-prototypes

// ---------------------------------------------------------------------------
// Configuration — RUNTIME, set from the on-screen SETUP (no per-unit flashing)
// ---------------------------------------------------------------------------
// Mount ID and the paired hub(s) live in NVS; one binary serves every mount.
//
//   Enter setup : touch & hold the screen ~1.5 s (auto-entered when unpaired)
//   Flow        : tap CAM 1-5  →  scan lists hubs (SSID/MAC/signal)  →  tap
//                 your hub  →  SAVE  →  mount restarts paired.
//
// The hub needs no action: it learns this mount's MAC from the first packet
// (pairing rules in esp32_hub.ino).  Multiple hubs (e.g. home + work) can be
// paired; at boot — and whenever the active hub goes silent — the mount scans
// for any known hub and follows it, including onto a changed WiFi channel.

#include <Preferences.h>

// Scan filter.  BOTH prefixes are accepted, deliberately:
//
//   "PTS-"      the named hubs and satellites (esp32_hub_eth).  Four characters
//               so a location name ("Concert Hall", "Foyer") still fits the 16
//               usable characters of KnownHub::ssid and shows in full.
//   "CamMount"  the current production hub (esp32_hub), which is not renamed.
//
// Accepting both avoids a flag day: this mount firmware works against a rig
// that has not been touched AND against a test hub on the new board, so the
// two can be rolled out independently instead of everything having to change
// in one go.  Drop "CamMount" once no unnamed hub remains.
#define HUB_SSID_PREFIX      "PTS-"
#define HUB_SSID_PREFIX_OLD  "CamMount"
// Saved list, in NVS.  Mounts tour the building, so this is a HISTORY of every
// hub/satellite the mount has been paired to — not a snapshot of what is nearby.
// Requirement: at least 8, at most 16.  At 24 bytes an entry, 16 costs 388
// bytes of NVS, so there is no reason to sit below the ceiling.
#define MAX_KNOWN_HUBS   16
// Scan results and setup-screen rows.  Bounded by the 1.75" round panel, and
// four is plenty: the scan keeps the STRONGEST four and drops the rest, and
// there should never be more than that within range of one mount.
#define MAX_SCAN_ROWS    4

struct KnownHub {
    uint8_t mac[6];       // hub softAP BSSID == its ESP-NOW address
    uint8_t channel;      // last known channel (self-heals via rescan)
    char    ssid[17];
};

struct MountCfg {
    uint8_t  magic;       // CFG_MAGIC when valid
    uint8_t  mount_id;    // 1-5
    uint8_t  n_hubs;      // entries used in hubs[]
    uint8_t  last_hub;    // index of the hub currently in use
    KnownHub hubs[MAX_KNOWN_HUBS];
};
#define CFG_MAGIC 0xC3

static MountCfg    _cfg = {};
static Preferences _mount_prefs;
static bool        _cfg_valid   = false;
static uint8_t     _mount_id    = 0;      // runtime mount ID (0 = unpaired)
static uint8_t     _hub_mac[6]  = {};     // active hub ESP-NOW address
static uint8_t     _hub_channel = 1;
static bool        _setup_active = false; // SETUP screen is showing (declared
                                          // early: gates main/level touch zones)
// Set by CMD_RESCAN_BASES, acted on in hub_reacquire_poll().  A flag rather
// than reaching into the reacquire state directly, because that state is
// declared several hundred lines below the packet handler that sets this.
static volatile bool _reacq_requested = false;
static uint32_t      _reacq_hold_ms   = 0;   // stagger, so mounts scan one at a time

static bool        _pair_active  = false; // camera-pairing screen is showing —
                                          // same reason, and the touch zones
                                          // must not fire underneath it either

static void cfg_apply_active_hub() {
    const KnownHub &h = _cfg.hubs[_cfg.last_hub];
    memcpy(_hub_mac, h.mac, 6);
    _hub_channel = h.channel;
}

static void cfg_save() {
    _mount_prefs.begin("mcfg", false);
    _mount_prefs.putBytes("cfg", &_cfg, sizeof(_cfg));
    _mount_prefs.end();
}

// ---------------------------------------------------------------------------
// Deferred config save
// ---------------------------------------------------------------------------
// cfg_save() writes the whole MountCfg — 16 hub records, ~390 bytes — through
// NVS, and a flash erase/write of that size blocks for a good fraction of a
// second.  Calling it straight from hub_reacquire_poll(), which runs in loop(),
// put that stall in the path of every jog, look-at update and CV correction:
// one mount showed 213 ms loop peaks against 9-11 ms on mounts that were not
// roaming.  On a motion controller that is a visible hitch, not a statistic.
//
// What a roam actually changes is which hub we prefer and its channel — a
// CACHE.  It is rediscovered by scanning on the next boot regardless, so
// writing it the instant it changes buys almost nothing, and a mount flapping
// between two hubs would write flash every time it moved.
//
// So: mark it dirty and write once the choice has held still, and only while
// the mount is idle.  Explicit pairing does NOT use this — that is a
// deliberate act by an operator and must survive the power being pulled a
// second later.
#define CFG_SAVE_SETTLE_MS  30000UL
static bool     _cfg_dirty       = false;
static uint32_t _cfg_dirty_since = 0;

static void cfg_save_deferred() {
    _cfg_dirty       = true;
    _cfg_dirty_since = millis();
}


static void cfg_load() {
    // Zero first: a short read leaves the unwritten tail as-is, and we want
    // unused hub slots empty rather than stale.
    memset(&_cfg, 0, sizeof(_cfg));
    _mount_prefs.begin("mcfg", false);
    size_t n = _mount_prefs.getBytes("cfg", &_cfg, sizeof(_cfg));
    _mount_prefs.end();

    // Accept a SHORT read.  hubs[] is the last member, so a config written when
    // MAX_KNOWN_HUBS was smaller is a valid prefix of the current layout — the
    // saved entries land in exactly the right slots.  Insisting on an exact
    // size, as this used to, meant raising MAX_KNOWN_HUBS unpaired every mount
    // in the building and someone had to walk round with a stepladder.
    //
    // KnownHub's own layout must not change for this to hold: growing the ARRAY
    // is compatible, changing the ELEMENT is not.
    const size_t hdr      = offsetof(MountCfg, hubs);
    const size_t slots_in = (n > hdr) ? (n - hdr) / sizeof(KnownHub) : 0;
    _cfg_valid = (n >= hdr + sizeof(KnownHub) && n <= sizeof(_cfg) &&
                  _cfg.magic == CFG_MAGIC &&
                  _cfg.mount_id >= 1 && _cfg.mount_id <= 5 &&
                  _cfg.n_hubs >= 1 && _cfg.n_hubs <= MAX_KNOWN_HUBS &&
                  // don't trust an n_hubs claiming more entries than were read
                  _cfg.n_hubs <= slots_in &&
                  _cfg.last_hub < _cfg.n_hubs);
    if (_cfg_valid) {
        _mount_id = _cfg.mount_id;
        cfg_apply_active_hub();
    } else {
        memset(&_cfg, 0, sizeof(_cfg));
        _mount_id = 0;
    }
}


// ---------------------------------------------------------------------------
// Pin definitions
// ---------------------------------------------------------------------------

// QSPI display — CO5300 466×466
#define LCD_CS      12
#define LCD_SCLK    38
#define LCD_SDIO0    4
#define LCD_SDIO1    5
#define LCD_SDIO2    6
#define LCD_SDIO3    7
#define LCD_RESET   39
// No separate BL pin — brightness via gfx->setBrightness()

// Touch — CST9217  I2C addr 0x5A
#define TOUCH_SDA   15
#define TOUCH_SCL   14
#define TOUCH_INT   11
#define TOUCH_RST   40
#define TOUCH_ADDR  0x5A

// 43 and 44 are the S3's native UART0 pins, free for the Teensy ONLY because
// the console is on the USB Serial/JTAG peripheral instead — a separate block
// on the USB D-/D+ pins, not a UART at all. Which of the two `Serial` means is
// decided by one Tools-menu item, and getting it wrong is silent here rather
// than loud:
//
//   USB CDC On Boot ENABLED   Serial = USB Serial/JTAG.  43/44 are the Teensy's.
//   USB CDC On Boot disabled  Serial = UART0 ON 43/44 — every console print in
//                             this file is then injected into the Teensy's RX
//                             line, and the Teensy's replies collide with it.
//
// tools/build.sh pins CDCOnBoot=cdc in the FQBN, so a repo build cannot get
// this wrong. A build from the Arduino IDE with that menu item set the other
// way can, and the failure would look like a flaky Teensy link rather than a
// board setting. esp32_hub_eth carries the same guard; it matters more here,
// because a display resynchronises on a magic byte and a motor controller is
// being told where to move.
#if !ARDUINO_USB_CDC_ON_BOOT
  #error "Tools -> 'USB CDC On Boot' must be ENABLED. Otherwise Serial is UART0 on GPIO43/44, which is the Teensy link."
#endif

#define TEENSY_TX    43
#define TEENSY_RX    44
#define TEENSY_BAUD  115200

// ---------------------------------------------------------------------------
// Timeouts / intervals
// ---------------------------------------------------------------------------
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
void loop() {
    // MARK(x) charges everything since the previous mark to section x, so the
    // whole pass is accounted for and nothing hides between the sections. Same
    // pattern as the hub and the satellite.
    uint32_t _mark = micros();
    #define MARK(sec) do { uint32_t n_ = micros(); uint32_t d_ = n_ - _mark; \
                           if (d_ > _msec_max[sec]) _msec_max[sec] = d_; _mark = n_; } while (0)
    esp_task_wdt_reset();
    ble_cam_poll();

    // Health telemetry: worst gap between loop iterations ≈ worst iteration.
    {
        static uint32_t _prev_loop_ms2 = 0;
        uint32_t nowh = millis();
        if (_prev_loop_ms2) {
            uint32_t gap = nowh - _prev_loop_ms2;
            if (gap > _health_loop_max_ms)
                _health_loop_max_ms = (gap > 65535) ? 65535 : (uint16_t)gap;
        }
        _prev_loop_ms2 = nowh;
    }

    MARK(MSEC_TOP);
    // ── Teensy serial — drain BEFORE rendering so commands are never stale
    drain_teensy_serial();

    MARK(MSEC_TEENSY);
    // ── LVGL tick + render (may block up to ~50 ms on full redraws) ──────
    static uint32_t _prev_ms = 0;
    const uint32_t now = millis();
    lv_tick_inc(now - _prev_ms);
    _prev_ms = now;
#if UI_PROFILE
    _ui_flush_accum_us = 0;
    uint32_t _ui_t0 = micros();
#endif
    lv_timer_handler();
#if UI_PROFILE
    {
        uint16_t total = (uint16_t)((micros() - _ui_t0) / 1000UL);
        uint16_t flush = (uint16_t)(_ui_flush_accum_us / 1000UL);
        if (total > _ui_lvgl_max_ms)  _ui_lvgl_max_ms  = total;
        if (flush > _ui_flush_max_ms) _ui_flush_max_ms = flush;
#if UI_PROFILE >= 2
        uint16_t kpx = (uint16_t)(_ui_inval_accum_px / 1000UL);
        if (kpx > _ui_inval_max_kpx) _ui_inval_max_kpx = kpx;
        uint16_t big = (uint16_t)(_ui_inval_big_px / 1000UL);
        if (big > _ui_inval_big_kpx) _ui_inval_big_kpx = big;
        _ui_inval_accum_px = 0;
        _ui_inval_big_px   = 0;
#endif
    }
#endif

    MARK(MSEC_LVGL);
    // ── Teensy serial — drain AFTER rendering to catch bytes that arrived
    //    while LVGL was flushing to the display
    drain_teensy_serial();

    MARK(MSEC_TEENSY2);
    // ── Touch & hold (~1.5 s): main -> SETUP -> CAMERA PAIRING ───────────
    // Chained rather than given a button of its own: SETUP has no room left,
    // and pairing is a once-per-mount commissioning job for whoever built the
    // rig, not something an operator needs to find.
    if (_press_started_ms && (millis() - _press_started_ms >= SETUP_HOLD_MS)) {
        _press_started_ms = 0;
        if (!_setup_active && !_pair_active)      setup_enter();
        else if (_setup_active && !_pair_active)  campair_enter();
    }

    // ── SETUP scan poller + hub reacquire ────────────────────────────────
    setup_poll_scan();
    campair_poll(millis());
    hub_reacquire_poll();
    cfg_save_poll();

    // ── Display dim timeout (never while SETUP is open) ──────────────────
    if (!_dimmed && !_setup_active &&
            (millis() - _last_touch_ms >= DIM_TIMEOUT_MS)) {
        if (_level_active) {
            _level_active = false;
            lv_scr_load(_main_scr);
        }
        set_dim(true);
    }

    // ── Spirit level update ──────────────────────────────────────────────
    if (_level_active) {
        update_level_screen();
    }

    MARK(MSEC_UI);
    // ── ESP-NOW peer refresh / full reinit (flagged from the send callback,
    //    actioned here — esp_now_*() must never run in the WiFi task)
    if (_espnow_need_refresh) {
        _espnow_need_refresh = false;
        espnow_peer_refresh();
    }
    if (_espnow_need_reinit) {
        _espnow_need_reinit = false;
        uint32_t rn = millis();
        if (_espnow_last_reinit_ms &&
                (rn - _espnow_last_reinit_ms) < ESPNOW_REINIT_MIN_GAP_MS) {
            // Held off — see ESPNOW_REINIT_MIN_GAP_MS.  Reset the ladder so it
            // has to climb the full twelve failures again rather than
            // re-requesting on the very next four.
            _espnow_refresh_count = 0;
            _espnow_reinit_held++;
            if (_espnow_reinit_held == 1 || (_espnow_reinit_held % 10) == 0)
                Serial.printf("[ESP-NOW] reinit held off (%lu since boot) — "
                              "%lus since the last one\n",
                              (unsigned long)_espnow_reinit_held,
                              (unsigned long)((rn - _espnow_last_reinit_ms) / 1000UL));
        } else {
            _espnow_last_reinit_ms = rn ? rn : 1;
            espnow_full_reinit();
        }
    }

    MARK(MSEC_ESPNOW);
    // ── Refused sends → reboot (see NOMEM_RESTART_MS) ────────────────────
    // First in this section on purpose: it answers in three seconds a fault the
    // one-way detector below takes thirty to recognise, and then treats with a
    // WiFi-level restart that has never once held on a mount.  It shares that
    // detector's reboot quota — from the operator's chair these are the same
    // event — so a fault that a boot does not fix cannot boot-loop the mount;
    // past the quota the old ladder takes over, exactly as it was.
    //
    // Below the reboot, the ladder (see NOMEM_BLE_HOLD_MS) gets its three
    // chances first, on every pass while the run is open.
    if (NOMEM_RESTART_MS && _cfg_valid && !_setup_active && !_pair_active) {
        uint32_t since, last;
        portENTER_CRITICAL(&_nomem_mux);
        since = _nomem_since_ms;
        last  = _nomem_last_ms;
        portEXIT_CRITICAL(&_nomem_mux);
        if (since) nomem_ladder_step(since, millis());
        else       nomem_reserve_tend(millis());
        int32_t span = since ? (int32_t)(last - since) : -1;
        if (span >= (int32_t)NOMEM_RESTART_MS) {
            if (_wedge_reboots < TXWEDGE_MAX_REBOOTS) {
                _wedge_reboots++;
                nomem_stash_event((uint32_t)span);
                wedge_count_bump();     // persists across the restart AND a power cycle
                esp_restart();
            } else {
                static uint32_t moaned = 0;
                uint32_t nw = millis();
                if (!moaned || (nw - moaned) > 60000UL) {
                    moaned = nw ? nw : 1;
                    Serial.printf("[ESP-NOW] NO_MEM for %ldms but %d reboots already "
                                  "— leaving it to the old ladder\n",
                                  (long)span, TXWEDGE_MAX_REBOOTS);
                }
            }
        }
    }

    // ── One-way transmit wedge ───────────────────────────────────────────
    // Watched on the RATE of send failures, not on silence, so a mount that is
    // still receiving is not excused.  See TXWEDGE_FAILS_PER_S.
    {
        uint32_t nw    = millis();
        // Failures AND refusals.  This watched _espnow_fail_total alone, which
        // is incremented from the send callback — and a refusal never reaches
        // that callback, which is stated three functions up in this same file.
        // So the detector was blind to the exact fault it exists to catch.
        //
        // Measured 2026-08-15: mount 5 isolated twice, both times with the
        // queue full — 1770 refusals against txfail 680, then 1673 refusals
        // against txfail 15. The second is unambiguous: the radio was fine and
        // nothing was failing, the stack simply stopped accepting frames. TX
        // died a full 59 s before RX did, so there was a minute of exactly the
        // conditions this was written for, and it saw fifteen failures and did
        // nothing. Both ran on to a two-minute isolation and a full reboot.
        uint32_t fails = _espnow_fail_total + _espnow_tx_refused;
        bool rx_alive  = !clock_silent(nw, _last_hub_rx_ms, HUB_TIMEOUT_MS - 1);

        // Track when the failure counter last MOVED.  This is the only honest
        // measure of "recovered" available: nothing a remedy does can fake it.
        if (fails != _txw_quiet_val) { _txw_quiet_val = fails; _txw_quiet_ms = nw; }
        if (!_txw_quiet_ms) _txw_quiet_ms = nw;

        // A genuinely quiet spell hands the reboot quota back, so a wedge hours
        // ago does not leave the mount unable to rescue itself from the next.
        if (_wedge_reboots && (nw - _txw_quiet_ms) > TXWEDGE_CLEAR_MS)
            _wedge_reboots = 0;
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

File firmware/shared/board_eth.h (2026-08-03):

#pragma once
// ---------------------------------------------------------------------------
// Ethernet for the Waveshare ESP32-S3-ETH (W5500 over SPI, PoE variant).
// ---------------------------------------------------------------------------
// Both the hub and the satellites run this board, so the bring-up lives here.
//
// Pin map confirmed against Waveshare's ESP32-S3-ETH pinout diagram.
// eth_begin() still prints what it used at boot, so a board revision that moves
// something shows up as one line in the log rather than a silent failure:
//
//   [ETH] W5500 on SPI  cs=14 int=10 rst=9  sck=13 miso=12 mosi=11
//
// ALSO SPOKEN FOR on this board, do not reuse:
//   GPIO 4,5,6,7   microSD slot (CS, MISO, MOSI, CLK)
//   GPIO 19,20     USB D-/D+ — the PC app rides that link
//   GPIO 43,44     UART0, used for the 7" display (confirmed broken out, free)
//
// The Arduino ESP32 core (3.x) drives the W5500 natively via ETH.begin(), so
// there is no third-party Ethernet library to pin a version of.

#include <ETH.h>
#include <SPI.h>

#ifndef ETH_SPI_CS
#define ETH_SPI_CS    14   // ETH_CS
#define ETH_SPI_INT   10   // ETH_INT
#define ETH_SPI_RST    9   // ETH_RST
#define ETH_SPI_SCK   13   // ETH_CLK
#define ETH_SPI_MISO  12   // ETH_MISO
#define ETH_SPI_MOSI  11   // ETH_MOSI
#endif

// W5500 has no factory MAC, so one is derived from the ESP32's own — stable
// across reboots, unique per board, and no risk of two units colliding on the
// LAN the way a hard-coded literal would.
#ifndef ETH_PHY_ADDR
#define ETH_PHY_ADDR   1
#endif

// Name this node answers to, and how it appears in the DHCP server's lease
// list.  Set per sketch before including this header.
#ifndef ETH_HOSTNAME
#define ETH_HOSTNAME "pts-node"
#endif

// ---------------------------------------------------------------------------
// Static address (optional — DHCP is the default and the norm)
// ---------------------------------------------------------------------------
// Define these in the SKETCH, before including this header, never here: hub and
// satellites share this file, and a static address set here would hand every
// one of them the same IP.
//
//   #define ETH_STATIC_IP  "192.168.1.50"
//   #define ETH_GATEWAY    "192.168.1.1"
//
// Useful when the DHCP server only serves registered MACs and this board is not
// on the list yet — the chicken-and-egg where you need the lease to find the
// board and the board to find the MAC.  A static address sidesteps it, at the
// cost of being a second place the network is configured, so prefer getting the
// MAC registered and deleting these again.
#ifdef ETH_STATIC_IP
  #ifndef ETH_GATEWAY
    #error "ETH_STATIC_IP also needs ETH_GATEWAY (the router, for anything off-subnet)"
  #endif
  #ifndef ETH_SUBNET
    #define ETH_SUBNET "255.255.255.0"
  #endif
  #ifndef ETH_DNS
    #define ETH_DNS ETH_GATEWAY
  #endif
#endif

static bool _eth_up = false;

inline bool eth_is_up() { return _eth_up; }

inline void eth_on_event(arduino_event_id_t event) {
    switch (event) {
        case ARDUINO_EVENT_ETH_CONNECTED:
            Serial.println("[ETH] link up");
#ifdef ETH_STATIC_IP
            // Kept as insurance, not because it is known to be needed: a static
            // address is set before the link exists, so there might be no
            // GOT_IP to wait for, and _eth_up staying false would mean the
            // satellite uplink never attempts a connection with nothing in the
            // log to say why.  On a W5500 with core 3.3.11 GOT_IP does fire, so
            // this is normally redundant — it does not print, or the address
            // would appear twice on every link-up.
            _eth_up = true;
#endif
            break;
        case ARDUINO_EVENT_ETH_GOT_IP:
            _eth_up = true;
            Serial.printf("[ETH] %s  gw %s\n",
                          ETH.localIP().toString().c_str(),
                          ETH.gatewayIP().toString().c_str());
            break;
        case ARDUINO_EVENT_ETH_LOST_IP:
        case ARDUINO_EVENT_ETH_DISCONNECTED:
        case ARDUINO_EVENT_ETH_STOP:
            if (_eth_up) Serial.println("[ETH] link down");
            _eth_up = false;
            break;
        default:
            break;
    }
}
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

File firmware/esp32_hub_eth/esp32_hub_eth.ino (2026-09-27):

/*
 * esp32_hub_eth — the hub firmware, for both hub boards.
 *
 * One source, two builds, chosen by the board it is compiled for (HUB_WIRED,
 * below):
 *
 *   Waveshare ESP32-S3-ETH     The wired hub (HUB_WIRED 1).  Ethernet — a W5500
 *                              over SPI, PoE — to the satellites, which serve
 *                              mounts too far from this hub's radio.
 *   Seeed Studio XIAO ESP32S3  The simple kit (HUB_WIRED 0): hub, phone and game
 *                              controller.  WiFi only — no Ethernet chip, so no
 *                              satellites.  Everything else is this same code.
 *
 * Until 2026-09-26 the XIAO ran its own firmware, esp32_hub/esp32_hub.ino.  It
 * fell a month behind this one — no recovery ladders, no stall detector, no hub
 * name — which is what two copies of one hub always do.  Now there is one.  The
 * folder keeps its old name so existing build setups keep working.
 *
 * web_app.h and hub_types.h are INCLUDED from ../shared/, not copied — a second
 * copy of either is exactly how the 9-byte STATUS bug happened.
 *
 * Architecture:
 *   [PC 1]    ── TCP (port 7777) ──┐
 *   [PC 2]    ── TCP (port 7777) ──┤
 *   [PC USB]  ── Serial 921600   ──┤── Hub ───────────────┬── Mount 1 ESP32
 *   [Phone]   ── WS  (port 80)   ──┘   (WiFi AP+ESP-NOW)  ├── Mount 2 ESP32
 *   [Tablet]  ── WS  (port 80)         │        │         ├── Mount 3 ESP32
 *                                UART  │        │ Ethernet├── Mount 4 ESP32
 *                    Waveshare display ┘        │ (wired  └── Mount 5 ESP32
 *                    (optional)                 │  build)
 *                                          [satellites] ───── distant mounts
 *
 * UART wiring to the optional display (3 wires), the same pins on both boards —
 * GPIO43/44 are D6/D7 on the XIAO:
 *   Hub GPIO43 (TX)  →  Waveshare display GPIO13 (RX)
 *   Hub GPIO44 (RX)  ←  Waveshare display GPIO12 (TX)
 *   Hub GND          —  Waveshare display GND
 *
 * Arduino IDE board settings.  These must match tools/build.sh — the scripted
 * build is the one that gets flashed, and a Tools-menu difference produces a
 * different binary from the same source.
 *
 *   Waveshare ESP32-S3-ETH   (build.sh "hubeth", FQBN_HUBETH):
 *     Board            : ESP32S3 Dev Module
 *     USB CDC On Boot  : Enabled
 *     USB Mode         : Hardware CDC and JTAG
 *     Flash Size       : 16MB (128Mb)
 *     Partition Scheme : 8M with spiffs (3MB APP/1.5MB SPIFFS)
 *     PSRAM            : Disabled
 *
 *   Seeed Studio XIAO ESP32S3   (build.sh "hub", FQBN_HUB):
 *     Board            : XIAO_ESP32S3
 *     USB CDC On Boot  : Enabled   (the XIAO's menu key for this is "default")
 *     USB Mode         : Hardware CDC and JTAG
 *     Flash Size       : 8MB (64Mb)
 *     Partition Scheme : Default with spiffs (3MB APP/1.5MB SPIFFS)
 *
 * On the USB mode, which is a real trade-off and not a free choice.  The S3
 * wires the host's DTR/RTS straight to reset and boot0 in silicon — that is
 * precisely what lets esptool flash this board with no BOOT button.  The same
 * wire means the PC can reset the hub simply by opening or closing the port,
 * and NOTHING in firmware can prevent it: enableReboot() exists only on the
 * TinyUSB USBCDC class, not on HWCDC.
 *
 * So: Hardware CDC keeps flashing button-free and accepts that the host can
 * reset the hub.  USB-OTG (TinyUSB) can refuse the reset via
 * Serial.enableReboot(false) — which is why the old XIAO firmware demanded it —
 * but then reflashing needs BOOT held, RESET tapped, released, upload.  The
 * VID/PID changes too, so Windows may hand out a new COM port.  Hardware CDC is
 * chosen for both boards: the wired hub lives in an enclosure, and the simple
 * kit is for people whose only use for a PC is flashing.
 *
 * Requires libraries:
 *   mathieucarbou/ESPAsyncWebServer  (ESP-IDF v5 compatible fork)
 *   mathieucarbou/AsyncTCP
 */

// ---------------------------------------------------------------------------
// Which hub this is
// ---------------------------------------------------------------------------
//   1  the wired hub: Ethernet brought up, satellites listened for
//   0  the XIAO, WiFi only: neither.  The satellite code still compiles but
//      never runs — nothing can connect without the listener — so every mount
//      is routed over this hub's own radio, which is what "direct" means.
//
// Chosen from the board the sketch is compiled for; -DHUB_WIRED=0/1 overrides.
#ifndef HUB_WIRED
  #if defined(ARDUINO_XIAO_ESP32S3)
    #define HUB_WIRED 0
  #else
    #define HUB_WIRED 1
  #endif
#endif

#include <WiFi.h>
#include <esp_wifi.h>
#include <esp_now.h>
#include <freertos/queue.h>
#include <ESPAsyncWebServer.h>
#include <esp_task_wdt.h>
#include <esp_system.h>   // esp_reset_reason()
#include <esp_mac.h>      // esp_read_mac() — MAC-derived default hub name
#include <lwip/sockets.h> // SOL_SOCKET / SO_SNDTIMEO for the satellite link
#include "../shared/disp_uart.h"
#include "../shared/web_app.h"
#include "../shared/hub_types.h"
#include "../shared/names.h"      // camera and position names, shared by every client
#include <ESPmDNS.h>
// sat_link.h first: it owns the hostname, and board_eth.h needs it to have been
// defined by the time it is included.
#include "../shared/sat_link.h"
#define ETH_HOSTNAME SAT_HUB_HOSTNAME

// The hub takes its wired address from DHCP.  The network now serves one, and
// the hub and every satellite are registered on it, so there is nothing to
// configure here — the address it received is printed at boot alongside the
// Ethernet MAC.
//
// Define these three again to pin a static address instead.  That is worth
// doing when the DHCP server only serves registered MACs and this board is not
// on the list yet: the chicken-and-egg where you need the lease to find the
// board and the board to find the MAC.  It costs you a second place the network
// is configured, so prefer registering the MAC and commenting them out again.
//
// ETH_DNS follows ETH_GATEWAY when unset, and mDNS resolves "pts-sat*.local"
// by multicast rather than by asking a server, so it is not usually needed.
//#define ETH_STATIC_IP  "192.169.1.10"
//#define ETH_SUBNET     "255.255.255.0"
//#define ETH_GATEWAY    "192.169.1.1"

#if HUB_WIRED
#include "../shared/board_eth.h"   // W5500 pins and bring-up — the wired board only
#endif
#include "../shared/crash_report.h"   // RelayMsg — must be last so it follows all other includes
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

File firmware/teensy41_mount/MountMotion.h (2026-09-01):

#pragma once
/*
 * MountMotion — Teensy 4.1 camera mount motion library
 *
 * Wraps TeensyStep4 for synchronised multi-axis moves with acceleration.
 * Controls four TMC2209 drivers, each on a dedicated bidirectional serial port.
 *
 * TMC2209 UART — one per axis, full duplex (TX + RX), all drivers at address 0.
 *   PAN    → Serial5  (TX=20, RX=21)
 *   TILT   → Serial4  (TX=17, RX=16)
 *   SLIDER → Serial3  (TX=14, RX=15)
 *   ZOOM   → Serial8  (TX=35, RX=34)
 *   MS1 = GND, MS2 = GND on every board (address 0, no multiplexing).
 *   Wiring per driver:  TX ─ 1kΩ ─ PDN_UART ← RX
 *
 * StallGuard via DIAG1 pin (hardware interrupt-capable):
 *   DIAG1 configured push-pull, goes HIGH on stall.
 *   PAN DIAG→3,  TILT DIAG→9,  SLIDER DIAG→13,  ZOOM DIAG→33
 *   Note: pin 13 doubles as the Teensy onboard LED; used here as input.
 *
 * Pin assignments are defined in MountMotion.cpp — adjust for your wiring.
 */

#include <Arduino.h>
#include <teensystep4.h>
#include <TMCStepper.h>
#include "protocol.h"

// ---------------------------------------------------------------------------
// Default StallGuard thresholds — also used in EepromConfig initialisation
// Order: PAN, TILT, SLIDER, ZOOM
// ---------------------------------------------------------------------------
constexpr uint8_t DEFAULT_STALL_THRESHOLD[4] = { 100, 100, 80, 80 };

// ---------------------------------------------------------------------------
// v2 — Look-at constants
// ---------------------------------------------------------------------------

// Update rate for the look-at controller (ms).  50 Hz is comfortable for smooth tracking.
#define LOOK_AT_INTERVAL_MS  20
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

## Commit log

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2026-07-12 Protocol single source of truth: canonical header + cross-checker + hook
    firmware/shared/protocol.h is now the canonical protocol definition,
    enforced by tools/check_protocol.py (run by .githooks/pre-commit):
    - verifies pc_app/comms/protocol.py enums/constants match the header
    - verifies the JS constants embedded in esp32_hub/web_app.h match
    - verifies teensy41_mount/protocol.h stays a one-line shim
    - golden cross-language test: compiles the real header, builds packets in
    C and Python, byte-compares both directions, CRC known-answer vectors,
    resync-after-garbage, corrupt-CRC and truncation rejection
    Drift found and fixed by the first run:
    - teensy41_mount/protocol.h had drifted badly (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
    [bridge.py, protocol.h, protocol.py]
2026-07-12 Hub: autonomous self-recovery — wedge ladder + maintenance restart
    The hub->mount TX wedge was previously detected and recovered only by the
    PC app (CMD_HUB_REINIT_ESPNOW / CMD_HUB_RESTART escalation). A hub running
    with just the hub display stayed wedged until power-cycled. The hub now
    recovers itself:
    Wedge detection (no PC needed):
    - _espnow_fail_run[]: uninterrupted send-FAIL run per mount, reset on success
    - wedge = sends failing (>=2 in a row) while that mount's STATUS keeps
    arriving (alive within 7 s) — the exact per-mount signature from the
    June logs; out-of-range mounts can't trip it (alive goes false first)
    - ladder: 6 s -> full ESP-NOW reinit (30 s cooldown shared with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
    [bridge.py, protocol.h]
2026-07-13 Hub: NVS paired-mount table — zero MAC addresses in source (pairing stage 1)
    Replaces the hard-coded MOUNT_MACS[] (with its home/work comment-swap) with
    a runtime {MAC -> slot} table persisted in NVS and learned by first contact.
    Every packet a mount sends carries the mount ID chosen on its touchscreen;
    the hub applies three binding rules to the first parsed packet per message:
    1. new MAC -> empty slot : bind + persist (first contact)
    2. known MAC -> different empty slot : move binding (mount renumbered);
    old slot freed + display told
    3. any MAC -> slot owned by other : reject + log + HUB_EVENT; kept in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
    [bridge.py, protocol.h]
2026-07-13 AMOLED: on-screen pairing setup — zero per-unit config (pairing stage 2)
    Removes MOUNT_ID / HUB_MAC / HUB_CHANNEL #defines (and the home/work hub
    comment swap). Identity now lives in NVS, set from the touchscreen; one
    binary serves every mount.
    SETUP screen (touch & hold ~1.5 s anywhere; auto-opens when unpaired):
    - CAM 1-5 buttons (each ringed in its mount accent colour)
    - async WiFi scan lists hubs matching HUB_SSID_PREFIX with MAC tail +
    signal; exactly one found -> preselected; scan wanders channels so the
    active hub channel is restored after every scan
    - SAVE merges the hub into a known-hubs list (up to 4), persists, restarts
    - shows this mount's own MAC for remote support
    Mult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
    [esp_mount_amoled175.ino, teensy41_mount.ino]
2026-07-13 Hub display: conflict prompt + Mounts panel (pairing stage 3)
    Completes the touchscreen pairing system — the hub display now surfaces
    the two pairing interactions that previously lived only in serial logs:
    Conflict prompt (auto-appears, floats over any screen):
    - 'New device <MAC> claims CAM n — bound to <MAC>' with REPLACE / IGNORE
    - REPLACE re-binds the slot to the new device (frees the claimant's old
    slot if it had one, evicts the previous owner's ESP-NOW peer)
    - IGNORE suppresses that device+slot until the hub reboots
    - prompt auto-dismisses if the claimant goes quiet for 10 s (renumbered
    on its own screen or powered off)
    Mounts panel ('Mounts' button in the top bar of every sc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
    [esp32_display.ino, hub_display.cpp]
2026-07-14 Uniform health telemetry: CMD_HEALTH from every node into the PC log
    Every node now emits a 24-byte CMD_HEALTH record every 10 s (plus an
    immediate anomaly-flagged send on first boot report, low heap, loop
    stall, or a TX-fail jump): uptime, free heap, minimum-ever heap, worst
    loop/task iteration, cumulative link failures, RSSI, reset reason, and
    one node-specific counter (hub=ghost drops, bridge=ESP-NOW reinits).
    Traffic cost as designed: ~1 extra ESP-NOW frame/s network-wide (~0.4%
    of the existing 50 Hz STATUS load). Slow data rides its own slow
    packet — deliberately NOT piggybacked on the 50 Hz STATUS, which would
    cost ~200x more bytes. The bridge defers its periodic send while jog
    tr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
    [bridge.py, esp_mount_amoled175.ino, hub_display.cpp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]
2026-07-14 Teensy: close the one dead-man gap — zoom jogged during look-at moves
    Audit of the Teensy's motion-side dead-man behaviour (does the mount stop
    itself if the upstream link dies mid-motion, regardless of what the bridge
    or hub are doing):
    VERIFIED SOLID:
    - jog()/jogPanTilt()/jogSliderZoom() all stamp _jog_last_ms; _updateJog()
    stops ALL axes via stopAll() after JOG_WATCHDOG_MS (500 ms) of silence,
    with correct handling of an already-decelerating stop
    - LANC zoom has its own independent 500 ms watchdog, active in every state
    - bounded moves (GOTO, GOTO_SLOT, look-at slider, pre-aim, homing) are
    self-terminating — no dead-man needed
    - CMD_E_STOP -> emergencyStop() hard-stops all axes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
    [MountMotion.cpp]
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2026-07-20 Display: fix Positions-screen OOM crash/hang and vertical sync jumping
    Two hardware-verified fixes for the 7" hub console:
    - LVGL memory: the v2 UI (Mounts panel, conflict prompt, Positions' 50-button
    grid) outgrew the pool — building the Positions screen exhausted it, so
    lv_malloc() returned NULL mid-build: StoreProhibited via get_local_style()'s
    unchecked realloc, or a silent hang, and starved draw allocations glitched
    renders. init_lvgl() now adds 8 x 32 KB PSRAM overflow pools; 32 KB because
    a TLSF compiled for the 64 KB default pool silently rejects pools > 64 KB
    (a stale .build/ predating libraries/lv_conf.h bakes that default in —
    rebuild clean after touching lv_con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
    [hub_display.cpp]
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2026-07-20 Pairing management from the web app and PC app, not just the console
    Viewing, resolving conflicts (set), and forgetting (clear) mounts lived only
    on the 7" hub display, wired over its private UART. A hub + phone (or PC) rig
    had no way to resolve a same-number conflict or forget a retired mount.
    The hub already owned all the pairing logic (mount table in NVS, pair_decide/
    pair_forget, conflict detection) — it just wasn't exposed to network clients.
    This surfaces it:
    - protocol.h: 5 client-facing hub-scoped commands — GET_MOUNT_TABLE, MOUNT_TABLE,
    PAIR_CONFLICT, PAIR_DECIDE, PAIR_FORGET — mirroring the disp_uart.h payloads.
    Mirrored into pc_app/comms/protocol.py and web_app.h JS (c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
    [mount_manager.py, protocol.h, protocol.py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]
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2026-07-21 AMOLED/display: fix sheared partial redraws and missing-glyph text
    Three on-screen rendering problems found on real hardware:
    - SHEAR: the CO5300 AMOLED addresses columns in pairs, but the flush callback
    passed LVGL's raw area straight to the driver. A window starting on an odd
    column (or with an odd width) leaves the panel's write pointer misaligned, so
    every row lands a pixel over and the region renders sheared. Only small
    partial updates showed it — notably the centred SETUP status line, whose x1
    is (466 - text_width)/2 and so flips parity with the message: "Searching for
    hubs..." landed even and looked fine, "No hubs found..." landed odd and
    smeared. Round every invalida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
    [esp_mount_amoled175.ino, hub_display.cpp]
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2026-07-22 Hub display + web app: dormant slider dial, target flash, positions layout
    Real UI fixes surfaced by the demo (they apply to any rig, not just the demo):
    Hub display (hub_display.cpp):
    - Slider-less mount now renders its slider dial dormant (preset 0: dash, dark
    dots) on ALL three screens. It was already dormant on positions/detail but the
    HOME screen (hub_ui_update_preset) still showed the raw preset — cam 4 read 1.
    - The Positions screen never repainted from an incoming STATUS: disp_update_slots
    refreshed the home tiles and detail screen but not the positions rows, so a
    recall's amber/green transitions only appeared when the page was (re)opened.
    Now it repaints the changed cam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
    [hub_display.cpp, web_app.h]
2026-07-22 Web app: fix portrait position grid clipping in mobile Safari
    The portrait position grid was the flex:1 (shrinking) child while the joystick
    block was flex-shrink:0 (fixed). In mobile Safari the bottom toolbar leaves less
    height than standalone (home-screen) mode, so the fixed ~200px joystick starved
    the grid until its top row clipped — hence 'fine when added to the home screen'.
    Swapped the priority: the position grid now keeps its natural (2-row) height and
    never shrinks (flex:0 0 auto), and the joystick area flexes (flex:1) and sizes
    the joystick to the height it actually gets. So a short viewport shrinks the
    joystick (down to a 90px floor) instead of clipping the position buttons.
    Ve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
    [web_app.h]
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2026-07-23 docs: add Bill of materials manual page
    New docs/manual/bom.html, generated from BoM.xlsx: every part grouped by
    section (Circuit, Mount + video paths, Slider + video paths, Hub, Hub Display,
    Misc, Optional) with quantities and buy-links, plus per-assembly fastener
    lists derived from the Nuts&Bolts matrix -- laid out as cards rather than a
    wide 18-column table. Typos corrected on the page (monut->mount,
    teminals->terminals, 1.4w->1/4W). Added to the manual nav and linked from the
    Building page. BoM.xlsx included as the downloadable source.
    [BoM.xlsx]
2026-07-23 docs(bom): fastener matrix on the page + tidied spreadsheet with Totals
    Page: swap the per-assembly fastener cards for the concise fastener x assembly
    matrix (scrollable, sticky Fastener column) with a sticky Total column showing
    how many of each to buy.
    Spreadsheet: rebuild Parts as a clean grouped table (section banners, clickable
    vendor links, frozen header); fix the last typos (monut->mount, 1/4W, stray
    period); add a Total column to the fastener matrix. Converted that matrix from
    577 XLOOKUP formulas to static values + SUM totals so it opens correctly in any
    app (XLOOKUP evaluates only in Excel/Sheets/Numbers) -- the per-assembly
    Nuts&Bolts source sheet is kept untouched.
    Co-Authored-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
    [BoM.xlsx]
2026-07-23 docs(bom): remove M8 Washer (no longer used)
    Drop M8 Washer from the fastener matrix on the page and from the
    spreadsheet's Nuts&Bolts-List -- it was unused (zero across every assembly).
    [BoM.xlsx]
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2026-07-26 Hub display: CLEAR before SET on the per-camera screen
    Last surface still reading SET then CLEAR. Swap the two button x positions so
    it matches the web app (portrait, GC and extended) and the PC app; each button
    keeps its own colour, so SET stays the accent one. Manual's hub-detail.svg
    updated to match.
    [hub_display.cpp]
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2026-07-26 docs: refresh the manual BOM from the updated spreadsheet
    Picks up the corrected resistor value (10K -> 1K), the new UNC x 40 fastener
    and a second tripod-mount assembly. That new column arrived sharing the name
    "Tripod Mount" with the existing one, so rename it "Slider Tripod Mount" in
    both sheets -- two identically-named columns would have been unreadable on
    the page.
    [BoM.xlsx]
2026-07-26 docs: correct the UNC tripod fasteners to 1/4"
    They were recorded inconsistently as 3/8 UNC inserts and a "3/4 UNC 40mm"
    bolt, with the matrix calling the same bolt "UNC x 40". They are all 1/4 UNC
    tripod threads, and the bolt is 1½ inches, not 40 mm. Seven cells across both
    sheets now read "1/4 UNC Insert" and "1/4 UNC x 1½"", so the two sheets agree
    and the page regenerates from them.
    [BoM.xlsx]
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2026-07-26 docs: correct the 1/4 UNC insert supplier link
    Points at the insert that actually worked out best in use (B0B1F7NMJ5),
    replacing the first link recorded for it.
    [BoM.xlsx]
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2026-07-28 PC app: one lost ACK no longer reboots the hub
    _pending_acks is keyed by sequence number and an ACK removed only its own
    entry, so a single dropped ACK left a stale entry ageing for the full 60 s
    prune window. _oldest_overdue() reported it as a command still unacked, that
    crossed the 3 s wedge threshold, and the bridge escalated to CMD_HUB_REINIT
    then CMD_HUB_RESTART -- rebooting a healthy hub and dropping every mount with
    it. The reboot was the outage, not the fault it was reacting to.
    From the field log: mount 4 declared wedged at 18:15:39 having reported
    txfail 38 over 2 hours at a steady -76 dBm, ACKing every GET_CONFIG in
    ~150 ms, with the hub's own wedge detector never firing once. Tw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
    [bridge.py]
2026-07-29 Report the previous crash at boot, on the hub and the mount
    A panic left only "reset reason: PANIC(crash)" -- no fault address, no
    backtrace, and the panic text itself gone by the time anything reconnected.
    The ESP32 was already writing a core dump to flash on every panic; nothing
    ever read it back.
    crash_report_print() reads that dump on the next boot and prints the faulting
    task, its PC, the panic reason and a backtrace. On the hub this goes out over
    USB serial, which the PC app now extracts into comms.log as "HUB SERIAL:"
    lines -- so a crash is recoverable in the field with no cable attached, which
    is the whole point.
    No new partition or build flags needed: default_8MB.csv (used by both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
    [esp_mount_amoled175.ino]
2026-07-29 Web app: Find Limits for slider and zoom in the extended config
    The web app had Find Home but no Find Limits, so a hub-plus-phone rig -- no PC,
    no console -- could not measure an axis's travel, and a mount couldn't be set
    up from scratch on that setup at all. Adds a pair of side-by-side buttons at
    the bottom of each mount's config block, matching the console's layout.
    Sends CMD_FIND_LIMITS with the mount's stored StallGuard threshold, falling
    back to 80, exactly as the existing Find Home path does. Coloured orange
    rather than blue: unlike Home this drives the axis to BOTH ends, so it reads
    as distinct from the buttons above it, and it asks for confirmation first
    since it moves hardware.
    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
    [web_app.h]
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2026-07-30 PC app: wedge detection keys on ACKs, not on packets arriving
    The dominant field failure is a hub-side ESP-NOW SEND wedge: the hub keeps
    receiving from the mounts and forwarding their telemetry over USB, so every
    surface shows the mounts alive, while nothing sent to them arrives. The hub's
    own txfail counter freezes -- it stops attempting transmission entirely -- and
    the only confirmed cure is a full esp_restart(), which the escalation ladder
    already knows how to command.
    Detection had two defects, and fixing the first badly caused the second.
    The tracker flagged a wedge on any single command left unacked past
    WEDGE_DETECT_S. With ~10% steady-state packet loss on a healthy link that fires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
    [bridge.py]
2026-07-30 PC app: a short STATUS means "not reported", not "no look-at subject"
    On a look-at mount the stored-location border flickered red several times a
    second while the camera sat steady on the subject, mostly green with a red
    flash -- distracting on a mount that wasn't moving at all.
    Mount 5 emits two different STATUS lengths. send_status_heartbeat() in the
    mount bridge hand-rolls its own 9-byte packet:
    uint8_t p[9]; ... send_to_hub(CMD_STATUS, p, 9);
    while the shared builder in protocol.h sends 10, byte [9] being the active
    look-at subject. The hand-rolled copy predates that field and never gained it.
    decode_status() read the missing byte as 0xFF -- "no subject" -- so every
    heartbeat wip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
    [mount_manager.py, protocol.py]
2026-07-30 Teensy: raise slider default run current to 2000 mA
    DEFAULT_CURRENT_MA[SLIDER] 1000 -> 2000. Bench change made while testing the
    3 m rail; the slider carries the most load of any axis and 1000 mA left little
    margin for StallGuard to distinguish a real end stop from belt drag.
    Note this interacts with homing: StallGuard thresholds are tuned per camera
    against a given run current, so the stall behaviour on a mount flashed with
    this build may differ from one tuned at 1000 mA. Worth re-checking Find Limits
    per mount, alongside the outstanding slider soft-limit work.
    [MountMotion.cpp]
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2026-07-30 Mount: deselect the look-at subject on a nudge, and stop shipping a 9-byte STATUS
    Two bugs, one of which was hiding the other.
    STATUS is 10 bytes (shared/protocol.h build_status). The mount bridge's
    send_status_heartbeat() hand-rolled its own copy and emitted 9, dropping byte
    [9], the active look-at subject. Clients reading the absent byte as 0xFF saw
    "no subject", so a stored location flickered red ten times a second while the
    camera sat steady on it. The heartbeat now sends 10 bytes, and the bridge also
    takes byte [9] from the Teensy's STATUS rather than only from the event-driven
    CMD_LOOK_AT_STATUS, which had let its copy drift from the Teensy's truth.
    Fixing that revealed the second bu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
    [esp_mount_amoled175.ino, teensy41_mount.ino]
2026-07-30 PC app: log axis travel to comms.log, so slider overshoot can be measured
    The mounts have always broadcast CMD_POSITION -- pan/tilt in degrees, slider in
    millimetres, zoom in steps, plus a per-axis moving mask -- at 5 Hz while moving
    and 1 Hz at rest. Nothing consumed it: position_updated had zero subscribers
    and no surface anywhere displayed a position, so "how far did the slider
    actually travel?" was unanswerable from the PC app, the web app, the hub
    display and the mount screen alike.
    That is the blocker for the slider soft-limit work. The head runs past its
    recorded end and all we have is an eyeball estimate of 3-5 cm against a
    firmware margin of ~4.5 mm. Comparing the maximum reached d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
    [position_log.py]
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2026-08-01 Web app + hub display: look-at arrows from the mount, not the hub's echo
    Completes what 090ae12/a2f1142 started. All four surfaces now read the same
    field for the ◀/▶ arrows, so none of them can show motion the mount is not
    reporting.
    Both took their arrow state from CMD_LA_MOVE_DIR, which the hub injects as it
    relays the command. That is the hub's intent, not the mount's state, so a press
    lost on the radio left an arrow flashing for a move that never ran — and with
    no correcting signal it stayed that way. Both now derive it from target_slot in
    the relayed STATUS (TARGET_SLOT_LA_MIN/MAX), which the mount sets only when a
    look-at move genuinely starts and clears when the controller rel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
    [esp32_display.ino, hub_display.cpp, web_app.h]
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2026-08-01 Hub: a settable location name, carried in the AP SSID
    With satellites going into a building, "CamMount" on every unit would be
    unusable — a mount's setup screen would list four identical entries. Hubs now
    carry a location name: "Concert Hall", "Foyer", "Lecture Thtr".
    The name has to live in the SSID. A mount builds its setup list from a WiFi
    scan, before any ESP-NOW link exists, so the beacon is the only thing it can
    read at that moment; a name delivered over the protocol would arrive far too
    late to help choose. AP_SSID is therefore composed at boot rather than fixed:
    AP_SSID_PREFIX + name "PTS-" + "Concert Hall"
    The prefix drops from "CamMount" to "PTS-" because the mount s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
    [esp_mount_amoled175.ino]
2026-08-01 Shared: factor out the location name, add W5500 bring-up for the ETH board
    Hub and satellites will run the same Waveshare ESP32-S3-ETH, so the parts they
    both need move to firmware/shared/ rather than being copied. A divergent second
    copy of a wire-visible format is exactly how the 9-byte STATUS bug happened.
    hub_name.h — the location name and SSID composition, lifted verbatim from the
    hub. A mount cannot tell a hub from a satellite, so both must build their SSID
    by the same rule.
    board_eth.h — W5500 over SPI via the core's native ETH.begin(), so there is no
    third-party Ethernet library to pin. Non-blocking: DHCP completes on an event
    and the caller checks eth_is_up(), because a hub mu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
    [board_eth.h]
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2026-08-01 Hub: accept satellites and route each mount to whichever one serves it
    The other half of f808b31. The hub listens on SAT_LINK_PORT (7778), learns
    which satellite each mount is attached to, and sends downlink traffic there
    instead of into a radio that cannot reach it.
    Routing is LEARNED, never configured. A mount picks its own satellite — the
    strongest AP in its scan — so the hub finds out by seeing whose uplink the
    mount's traffic arrives on. Nothing to keep in step by hand, and a mount that
    roams carries its route with it. If a satellite drops, its mounts revert to
    local ESP-NOW rather than being left pointing at a dead socket.
    A satellite cannot be a pure byte pipe, which is the thin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
    [esp32_satellite.ino]
2026-08-01 Test hub in its own folder, on hardware CDC, leaving production untouched
    firmware/esp32_hub/ is restored to exactly what is running on the rig — byte
    identical to 467f11c. Three commits' worth of untested change (the location
    name, the shared-header refactor, the satellite listener and routing) move to
    firmware/esp32_hub_eth/, to be proven on the bench before the two are swapped.
    Hardware CDC rather than TinyUSB, which is a change from esp32_hub and the
    better default here. esp32_hub demands TinyUSB for Serial.enableReboot(false),
    which stops the host reopening the port from resetting it — an 80x/night reboot
    loop. But TinyUSB makes auto-reset-into-bootloader unreliable, so flashing ca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
    [esp32_hub_eth.ino, esp_mount_amoled175.ino]
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2026-08-02 PC app: a switched-off mount is not a wedge — stop restarting the hub for it
    Found on the test rig: powering the only mount off restarted the hub.
    18:52:40 cam1 last heard from (up 0.47h) <- switched off
    18:53:04 WEDGE mount=1
    18:53:28 commanding full hub restart
    18:53:30 HUB REBOOTED
    The three-way rule was in fff6bd1's commit message but only two thirds of it
    reached the code:
    ACKing -> healthy
    sending, no ACKs -> hub->mount SEND wedge, must escalate
    fully silent -> the mount is off or gone; the hub is fine
    Only the first was implemented as a skip. A fully silent mount fell through to
    "wedge". The mount-side branch that should have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
    [bridge.py]
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2026-08-03 Satellite: name it at build time, and give the hub the Ethernet it never had
    Two things a satellite needs before it can be deployed.
    NAMING. A satellite had no way to be named at all. It composed its SSID
    from NVS like the hub, but nothing on it could write that key, so every
    unit came up as "PTS-Hub-XXXX" off its MAC: announcing itself as a hub,
    and indistinguishable from the next one along in a mount's setup list.
    It is now named by the build, the only configuration a box with no UI can
    carry:
    SAT_NAME="Concert_Hall" tools/build.sh flash sat
    Unnamed it is "PTS-Sat-XXXX" — still unique, no longer claiming to be a
    hub. NVS is deliberately not consulted: this is the hub's board, a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
    [board_eth.h, esp32_hub_eth.ino, esp32_satellite.ino]
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
